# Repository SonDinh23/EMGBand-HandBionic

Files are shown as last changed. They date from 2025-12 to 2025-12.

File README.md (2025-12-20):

# ✋ EMGBand - Hand Bionic

<p align="center">
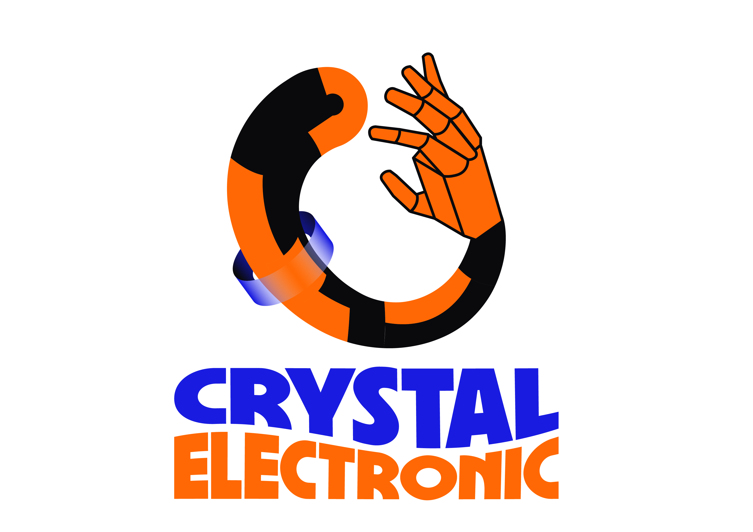
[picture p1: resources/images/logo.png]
EMGBand logo
	<br>
	<strong>Muscle intent in → bionic motion out.</strong>   
</p>

<p align="center">
	
	&nbsp;
	
</p>

EMGBand / Hand Bionic is a full-stack, open hardware kit that turns forearm muscle signals into predictable, servo-safe hand motion. It is built to be hackable, reproducible, and fast to demo: one bill of materials, one firmware pair (ring + hand), one Flutter app to calibrate and ship.

Designed for makers, researchers, and product teams, EMGBand focuses on reliability, safety, and repeatability. The repo bundles manufacturing-ready assets (Gerbers, BOMs), production photos, a tested ESP32 firmware pair, and a Flutter app that makes calibration and demos straightforward.

## Table of Contents
- 🔍 [What this repo delivers](#what-this-repo-delivers)
- 🖼️ [Quick gallery](#quick-gallery)
- 🧭 [Platform at a glance](#platform-at-a-glance)
- ⚙️ [Architecture snapshot](#architecture-snapshot)
- 📚 [Deep dives](#deep-dives)
- 🚀 [Fast start](#fast-start)
- ✨ [Tech highlights](#tech-highlights)
- 📜 [Licence](#licence)
- 🙏 [Thanks](#thanks)

| | | |
| --- | --- | --- |
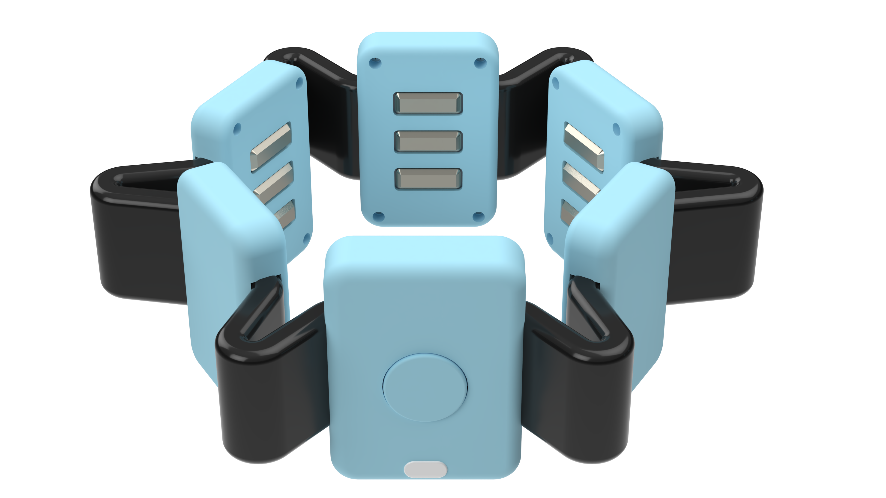
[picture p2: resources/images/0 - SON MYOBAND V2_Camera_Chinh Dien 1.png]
MyoBand front
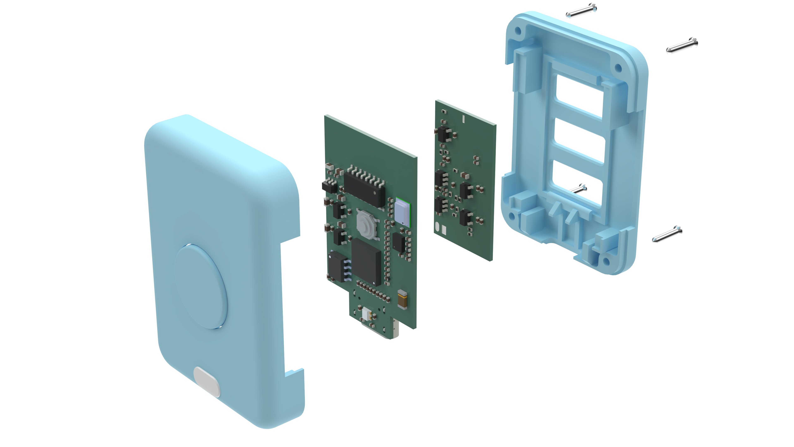
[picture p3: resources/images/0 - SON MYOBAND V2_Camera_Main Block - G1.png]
Main block
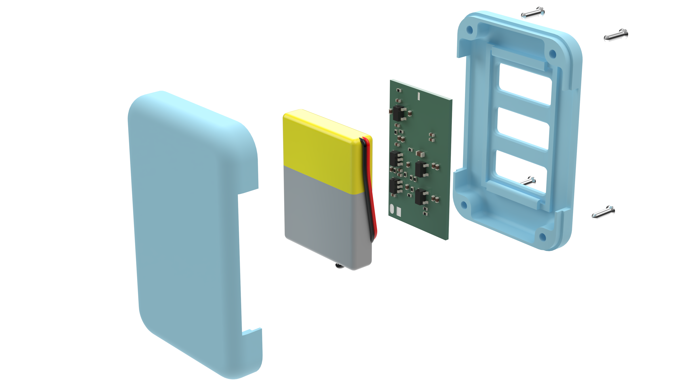
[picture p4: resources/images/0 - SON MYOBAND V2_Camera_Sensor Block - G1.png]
Sensor block
|  |  |  |

<p align="center"><sub>Wearable EMG ring + controller blocks from the latest build.</sub></p>

## What this repo delivers
- **Hardware you can fabricate**: KiCad projects for the MyoBand EMG front-end, hand controller, and modular sensor blocks. Gerbers, pick-and-place, and reference photos are ready for a quick manufacturing turn.
- **Firmware that guards the hardware**: ESP32 (ring + hand) stack with EMG filtering, intent classification, BLE services, OTA hooks, and stall-safe servo control so experiments stay repeatable and safe.
- **App that closes the loop**: Flutter client to scan, pair, stream EMG, calibrate thresholds (Line/Radar), push configs, and swap control modes without reflashing.
- **Media to build confidence**: Photos and demo videos to set assembly expectations before you order or solder.

## Quick gallery

See how the wearable comes together before diving into schematics or code.

| | | |
| --- | --- | --- |
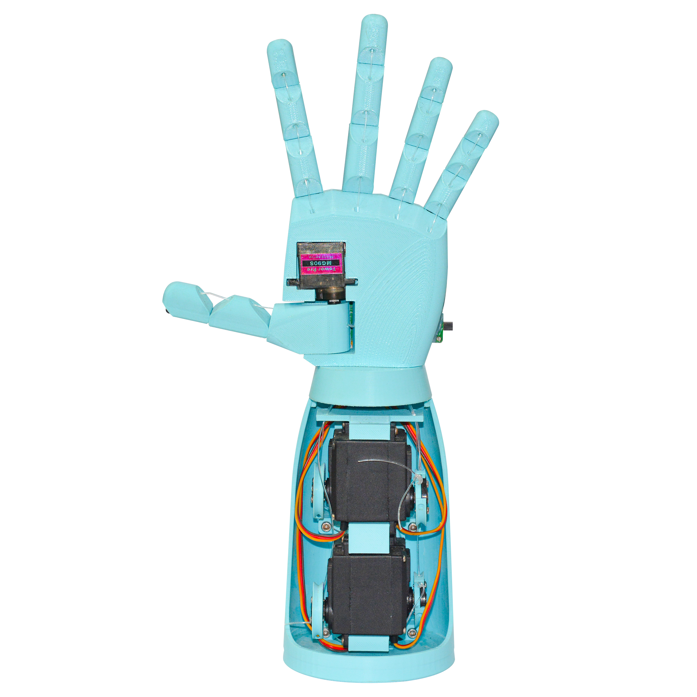
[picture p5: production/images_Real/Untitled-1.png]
Real build 1
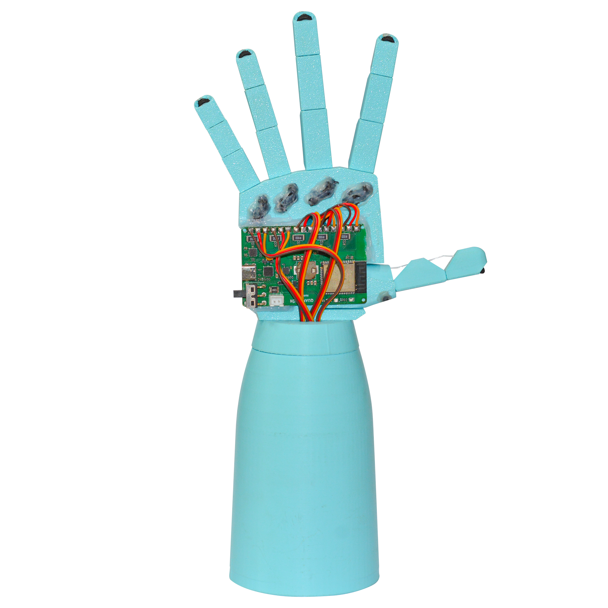
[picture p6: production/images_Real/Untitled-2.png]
Real build 2
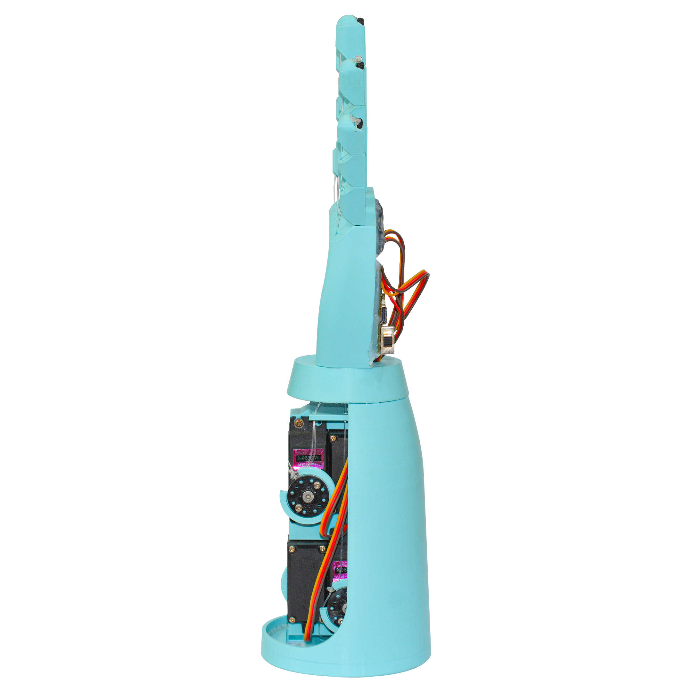
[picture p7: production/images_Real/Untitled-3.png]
Real build 3
| <br><small>📸 Assembled unit 1</small> | <br><small>📸 Assembled unit 2</small> | <br><small>📸 Assembled unit 3</small> |
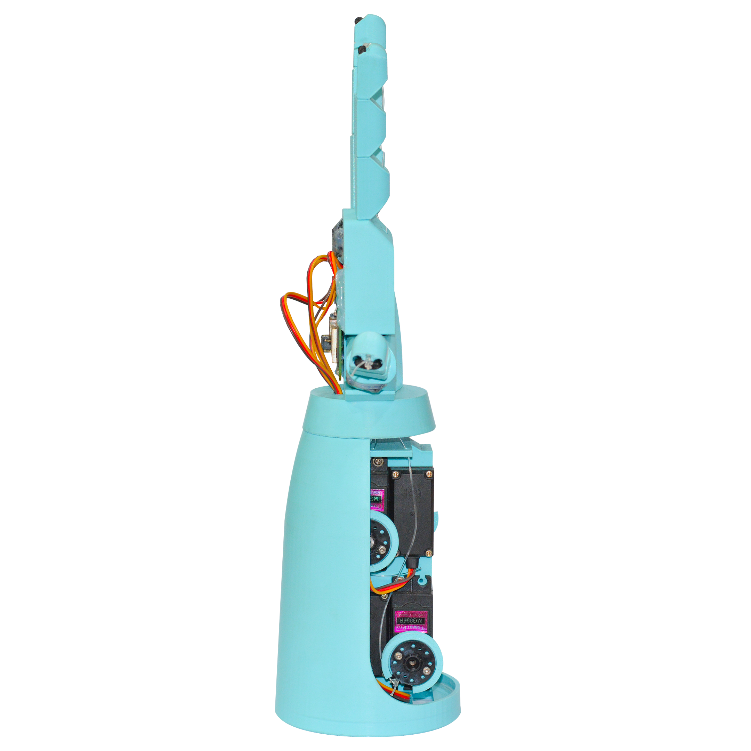
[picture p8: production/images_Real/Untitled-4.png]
Real build 4
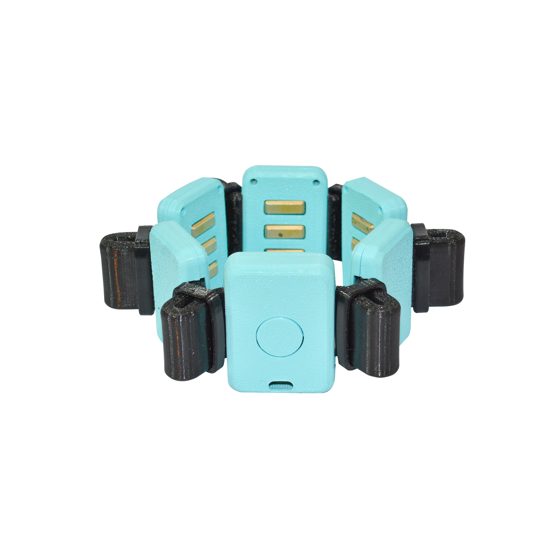
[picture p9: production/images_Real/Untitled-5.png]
Real build 5
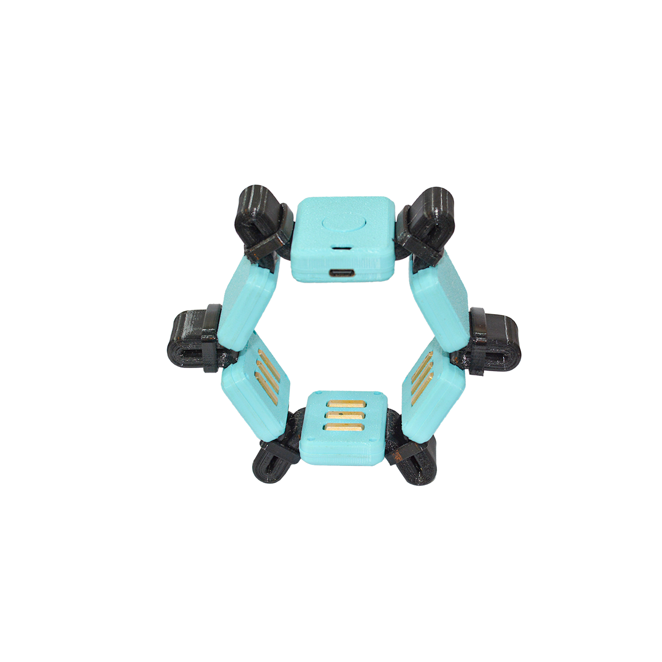
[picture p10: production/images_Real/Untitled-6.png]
Real build 6
| <br><small>🖼️ Side profile</small> | <br><small>🔬 Sensor block close-up</small> | <br><small>🔗 Strap view</small> |

<p align="center"><strong>Live demo videos</strong></p>
<p align="center">
	<video src="resources/video/Demo1.mp4" width="360" controls muted></video>
	<video src="resources/video/Demo2.mp4" width="360" controls muted></video>
</p>

<p align="center"><small>If embeds do not autoplay in your viewer, use the direct links: <a href="resources/video/Demo1.mp4">Demo1.mp4</a> · <a href="resources/video/Demo2.mp4">Demo2.mp4</a>.</small></p>

## Platform at a glance

| Layer | Highlights |
| --- | --- |
| 🛠️ **Hardware** | Low-noise EMG front-end, modular controller blocks, ready-to-manufacture assets, BOMs aligned to the photos you see. |
| 🧠 **Firmware** | ESP32 (ring + hand), FreeRTOS, NimBLE, OTA-ready, Line/Radar classifiers, servo current and motion guards to avoid stalls. |
| 📱 **App** | Flutter UX for BLE JSON control, half-float EMG streaming, auto pair/connect, per-user calibration, and live plots. |

## Architecture snapshot

Signal path in two stages: capture and clean EMG on the ring, classify intent and drive actuators on the hand controller. Calibration data lives in the app and syncs over BLE when you change modes.

<table>
	<tr>
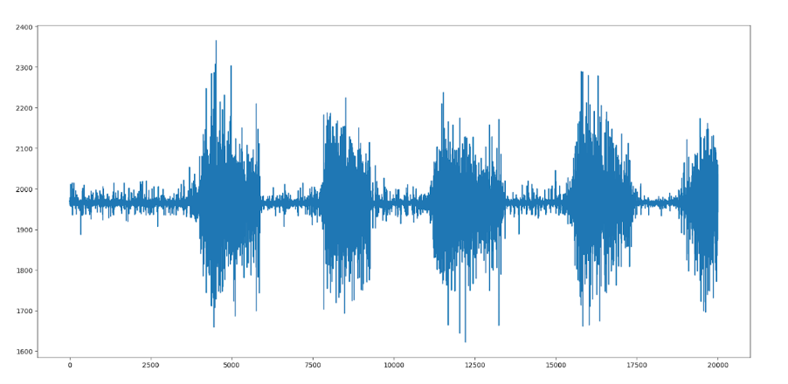
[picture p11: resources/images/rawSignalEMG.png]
Raw EMG
		<td align="center"><br><small>⚡ Raw EMG capture</small></td>
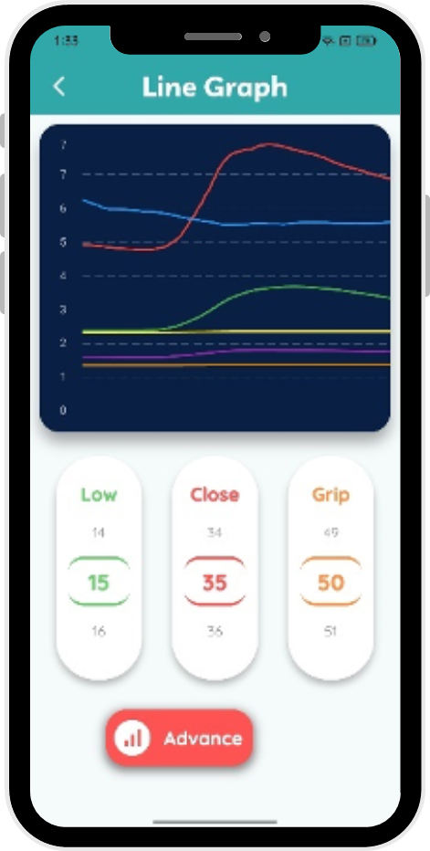
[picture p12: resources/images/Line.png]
Line mode
			<td align="center"><br><small>🔎 Line thresholds</small></td>
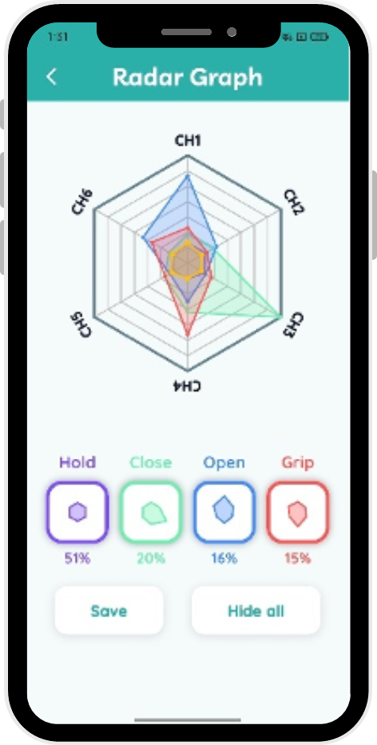
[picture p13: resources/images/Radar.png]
Radar mode
			<td align="center"><br><small>🔁 Radar/Spider matching</small></td>
	</tr>
	<tr>
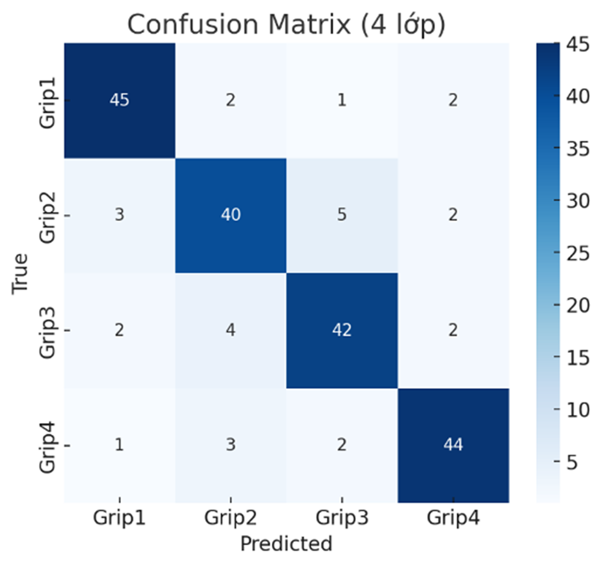
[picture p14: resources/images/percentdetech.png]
Detection percent
		<td align="center"><br><small>✅ Match confidence</small></td>
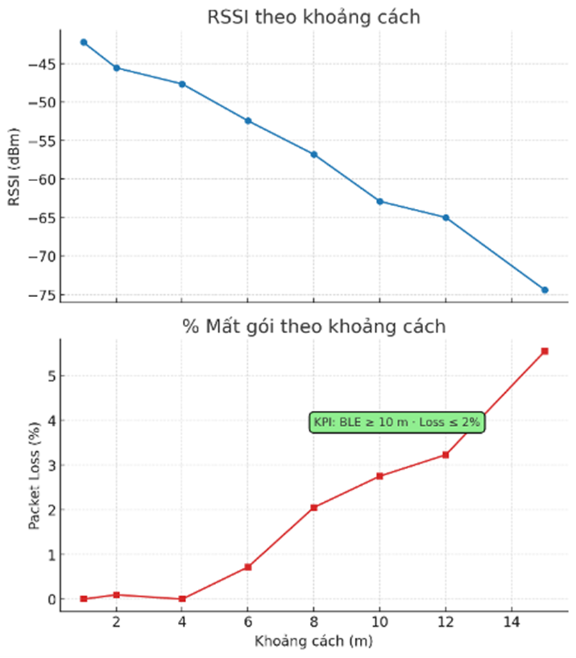
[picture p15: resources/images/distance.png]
Distance metric
		<td align="center"><br><small>➖ Similarity metric</small></td>
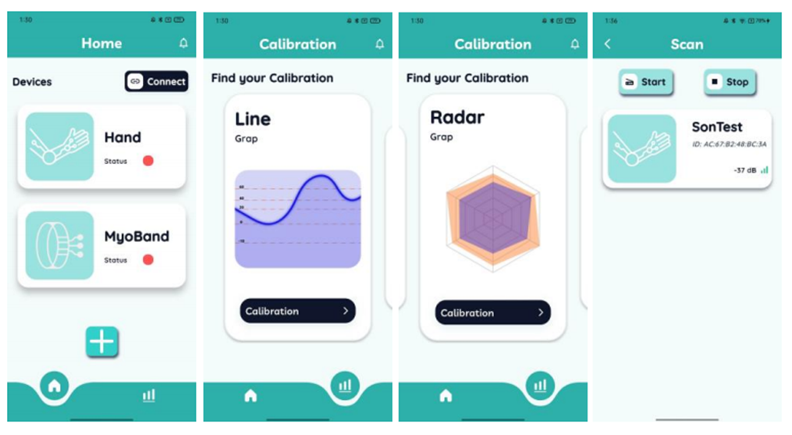
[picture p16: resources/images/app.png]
App UI
		<td align="center"><br><small>📱 Flutter app in action</small></td>
	</tr>
</table>

## Deep dives
- Hardware overview, IC map, and board variants: [hardware/README.md](hardware/README.md)
- Firmware flow, EMG filters/classifiers, BLE/OTA services: [firmware/README.md](firmware/README.md)
- App BLE flows, JSON protocol, half-float decode, and UI cues: [app/README.md](app/README.md)

## Fast start
1) **Fabricate / assemble**: pick your board set from [hardware](hardware/README.md); use the included Gerbers and assembly files to keep builds consistent with the photos.
2) **Flash firmware**: open `firmware/Embedded` in VS Code + PlatformIO, select the target (ring/hand), and run `pio run -t upload`.
3) **Pair with the app**: run the Flutter app (see [app/README.md](app/README.md)), scan and save Hand + MyoBand, then start EMG streaming.
4) **Calibrate deliberately**: choose Line or Radar, adjust thresholds/templates, push to devices, and watch the live plots to confirm stability.
5) **Demo safely**: use the stall/over-activity protections while you tune grip strength or motion ranges.

## Tech highlights
- Half-precision EMG streaming keeps BLE lean; float32 reconstruction happens in the app for analysis.
- Dual control modes: Line (summed thresholds for fast response) and Radar/Spider (template similarity, ≥70% match) for finer intent mapping.
- Safety nets: relax-before-use gating, over-activity clamps, current-based stall detection on servos, watchdog-backed tasks, and OTA hooks for quick fixes.
- UX polish: LED/buzzer cues, auto reconnect, smoothed charts, per-grip calibration profiles, and JSON-based control that is easy to script.

## Licence

This project is licensed under the GNU GPLv3.  
Compared to permissive licences like MIT, GPLv3 requires that if you modify this code and distribute your version (including in commercial products), you must also release your changes under the same GPLv3 licence and provide the corresponding source code.  

This way, everyone can benefit from improvements built on top of this project.  
If this licence causes issues for your intended use, feel free to contact me – I’m open to discussing alternatives.

## Thanks

Huge thanks to contributors, early testers, and the open-source toolchains that made this build possible. Enjoy hacking, and share what you build.

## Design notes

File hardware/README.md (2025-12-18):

# 🔧 Hardware Reference

The definitive pit stop for every PCB in the EMGBand/Hand Bionic stack. Each section tells you what the board does, how it talks to the rest, where to grab build assets, and what to check before you power it up—plus a gallery pulled straight from the committed files.

## 📌 At-a-glance

| Board | Role | Primary interfaces | Manufacturing kit |
| --- | --- | --- | --- |
| [Hand_main](#hand_main) | Bionic hand controller, Wi-Fi/BLE, power/rail monitor | USB-C, UART, GPIO, RGB LED | `Hand_main/*.kicad_*`, top/bottom photos |
| [myoband_main](#myoband_main) | Wearable hub for EMG/IMU/mic, power + comms | USB-UART, Wi-Fi/BLE, SPI/I2C/I2S, ADC | `myoband_main/*.kicad_*`, top/bottom photos |
| [myoBand_emg](#myoBand_emg) | EMG front-end with INA333 multi-stage filtering | Differential electrodes → analog out | `myoBand_emg/*.kicad_*`, top/bottom photos |
| [myoBand_emg_Renesas v0.2](#myoBand_emg_renesas-v02) | EMG front-end using ISL28533 | Differential electrodes → analog out | `myoBand_emg_Renesas/myoBand_emg_v0_2/*.kicad_*` |
| [myoBand_emg_Simulation](#myoBand_emg_simulation) | EMG filter/response simulation | N/A (SPICE) | `myoBand_emg_Simulation/*.kicad_*` |

---

## 🧠 Hand_main

### Highlights
- ESP32-WROOM-32D brain with Wi-Fi/BLE and a status RGB LED to keep you informed at a glance.
- INA3221 keeps eyes on three rails, so servos and external loads stay within safe current/voltage envelopes.
- TPS54620 buck + XC6220 LDO make clean rails; CP2102N USB–UART streamlines flashing and debug.

### Quick specs

| Parameter | Detail |
| --- | --- |
| MCU | ESP32-WROOM-32D |
| Power | Buck 5V→system, 3V3 LDO |
| Power monitor | INA3221 (3 channels) |
| Interfaces | USB-C/CP2102N, GPIO headers, WS2812 data |

### Manufacturing files
- [Hand_main/Hand_main.kicad_sch](Hand_main/Hand_main.kicad_sch)
- [Hand_main/Hand_main.kicad_pcb](Hand_main/Hand_main.kicad_pcb)
- [Hand_main/Hand_main.pdf](Hand_main/Hand_main.pdf)

### Build & test checklist
- Double-check buck polarity and place L/C exactly as laid out to keep EMI tame.
- Probe buck and 3V3 rails before seating the ESP32 or any sensitive loads.
- Confirm USB-C orientation/UART lines, then sanity-check INA3221 readings with a dummy load.

### Gallery

<table>
	<tr>
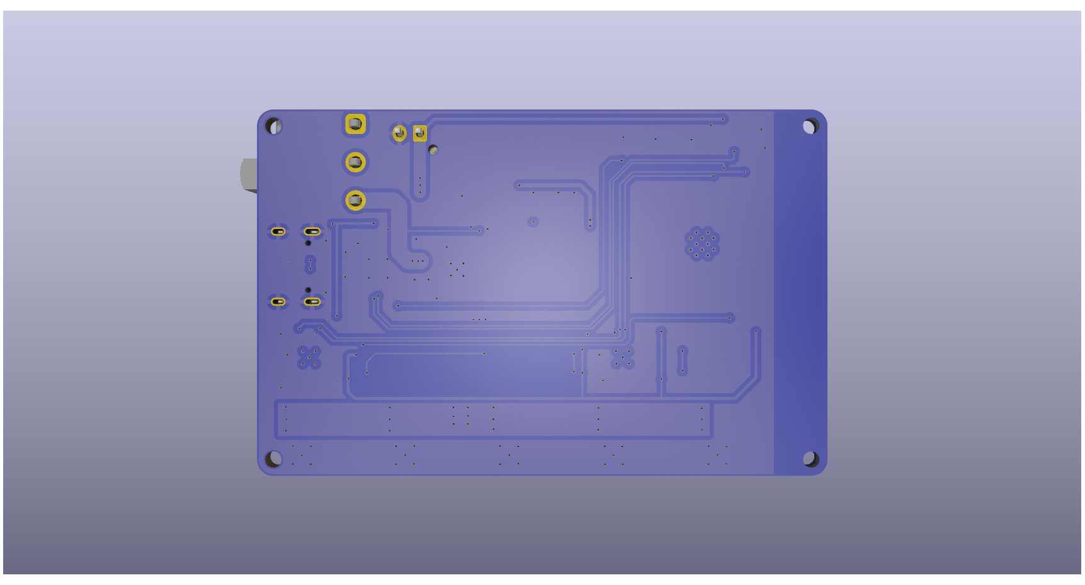
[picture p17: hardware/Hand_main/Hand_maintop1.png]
Hand_main top 1
		<td align="center"><br><small>Top — overview</small></td>
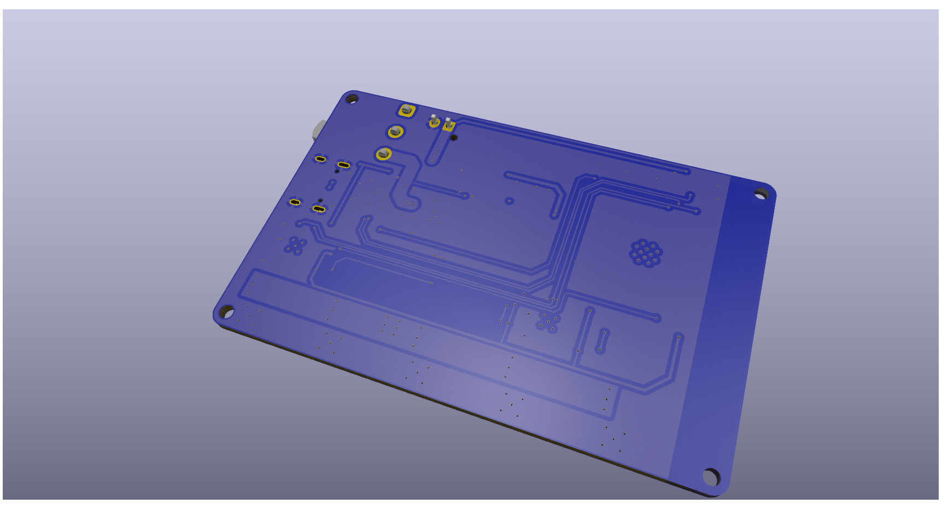
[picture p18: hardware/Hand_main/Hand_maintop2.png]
Hand_main top 2
		<td align="center"><br><small>Top — ESP32 & power</small></td>
	</tr>
	<tr>
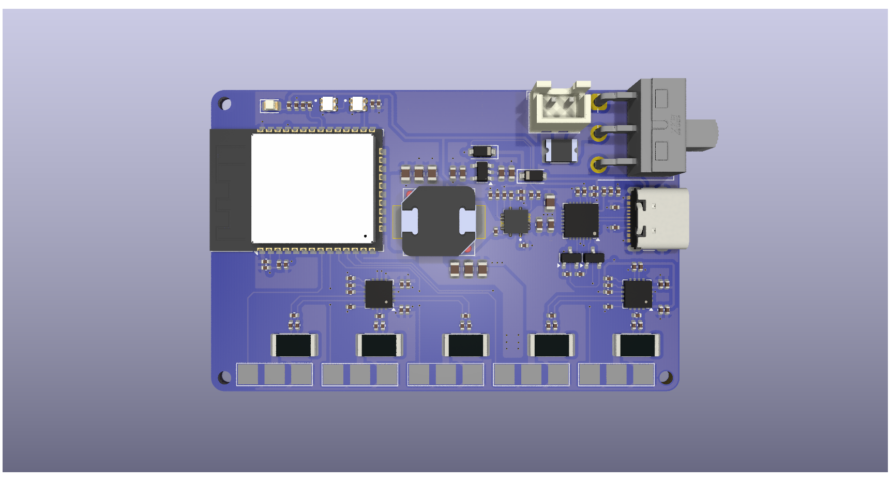
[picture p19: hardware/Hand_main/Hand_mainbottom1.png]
Hand_main bottom 1
		<td align="center"><br><small>Bottom — routing</small></td>
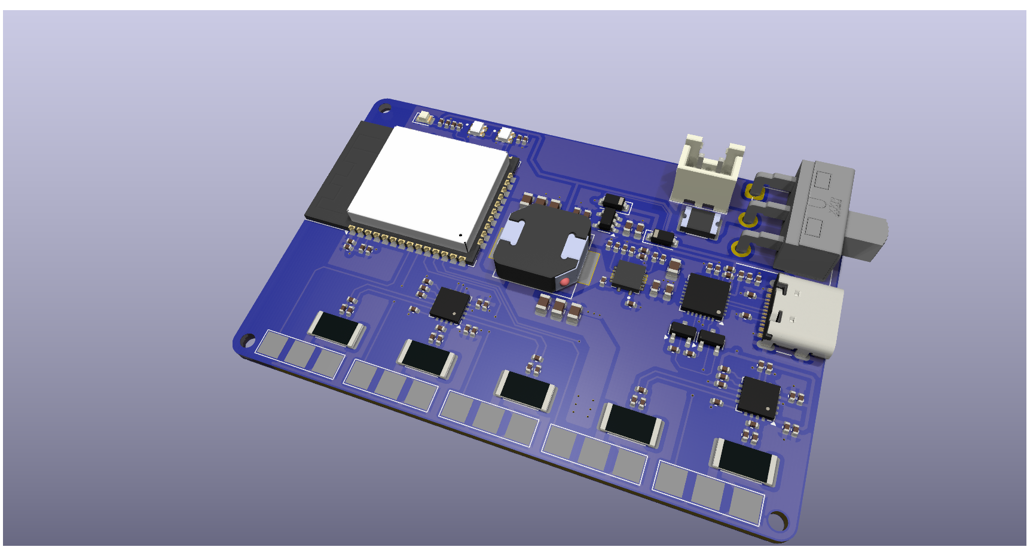
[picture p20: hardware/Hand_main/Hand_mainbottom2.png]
Hand_main bottom 2
		<td align="center"><br><small>Bottom — pours</small></td>
	</tr>
</table>

---

## 🧭 myoband_main

### Highlights
- ESP32-PICO-V3-02 wearable hub that ingests EMG (MCP3208), IMU data (LSM6DSL), and PDM audio (INMP441).
- Power spine: TP4056 Li-ion charger, 3V3 LDO for logic, TPS60402 negative rail for the analog front-end.
- CP2102N handles flashing/debug; WS2812B-2020 signals state; headers expose SPI/I2C/I2S for expansions.

### Quick specs

| Parameter | Detail |
| --- | --- |
| MCU | ESP32-PICO-V3-02 |
| EMG conversion | MCP3208 (12-bit SPI) |
| Sensors | IMU LSM6DSL, mic INMP441 |
| Power | TP4056 charger, 3V3 LDO, TPS60402 negative rail |
| Interfaces | Wi-Fi/BLE, USB-UART, SPI/I2C/I2S, GPIO |

### Manufacturing files
- [myoband_main/myoband_main.kicad_sch](myoband_main/myoband_main.kicad_sch)
- [myoband_main/myoband_main.kicad_pcb](myoband_main/myoband_main.kicad_pcb)
- [myoband_main/myoband_main.pdf](myoband_main/myoband_main.pdf)

### Build & test checklist
- Inspect TP4056 charge path and battery polarity; watch thermals at higher charge currents.
- Verify the TPS60402 negative rail before biasing the EMG analog stage.
- Smoke-test everything together: Wi-Fi/BLE, SPI EMG ADC, I2C IMU, PDM mic—and listen for noise coupling.

### Gallery

<table>
	<tr>
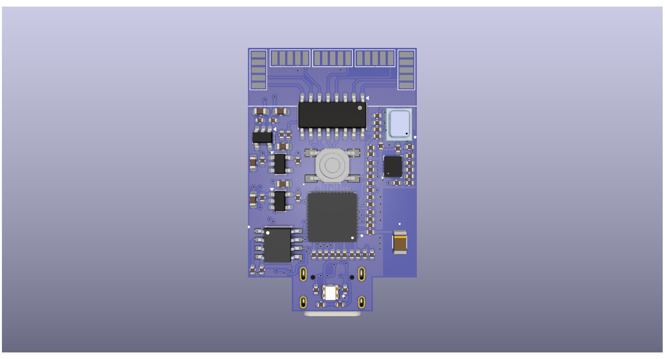
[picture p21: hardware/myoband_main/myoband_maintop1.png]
myoband_main top 1
		<td align="center"><br><small>Top — overview</small></td>
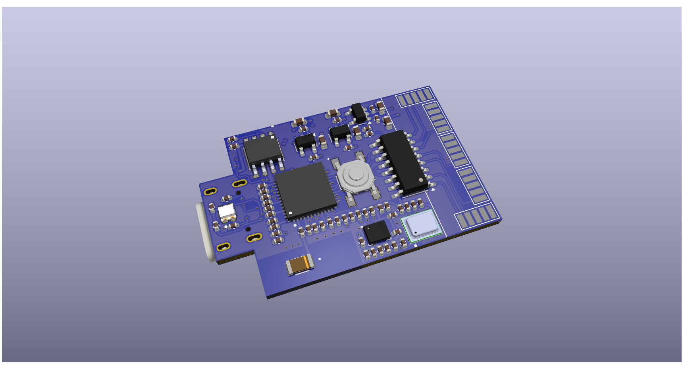
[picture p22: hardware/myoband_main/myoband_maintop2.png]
myoband_main top 2
		<td align="center"><br><small>Top — MCU & IO</small></td>
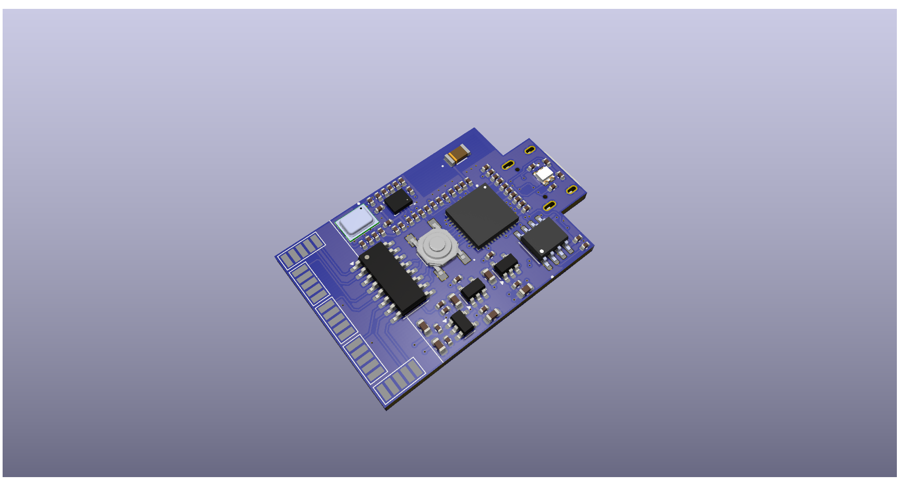
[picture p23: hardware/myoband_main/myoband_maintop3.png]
myoband_main top 3
		<td align="center"><br><small>Top — power/charger</small></td>
	</tr>
	<tr>
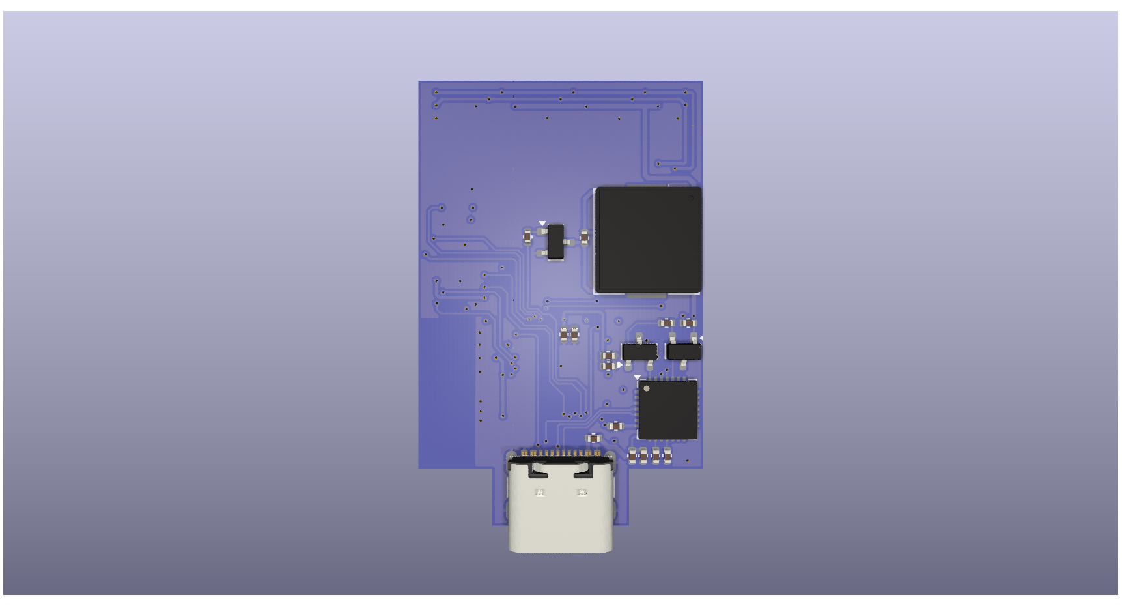
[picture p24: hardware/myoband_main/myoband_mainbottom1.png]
myoband_main bottom 1
		<td align="center"><br><small>Bottom — routing</small></td>
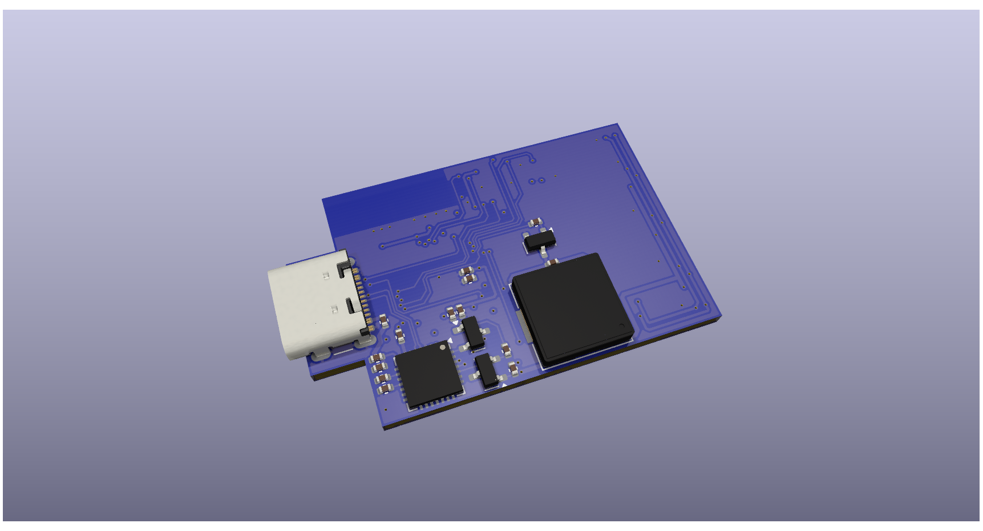
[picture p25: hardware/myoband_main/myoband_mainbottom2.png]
myoband_main bottom 2
		<td align="center"><br><small>Bottom — pours</small></td>
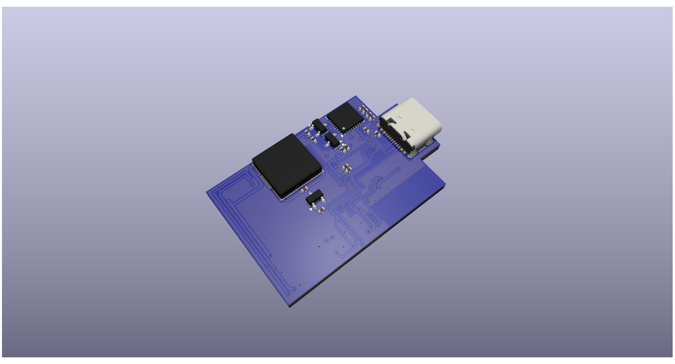
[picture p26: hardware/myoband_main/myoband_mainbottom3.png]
myoband_main bottom 3
		<td align="center"><br><small>Bottom — placement</small></td>
	</tr>
</table>

---

## 🩺 myoBand_emg (INA333)

### Highlights
- INA333-based EMG front-end for low-noise differential gain, feeding MCP601 stages for band-pass/notch shaping.
- TPS60402 negative rail preserves headroom and keeps distortion low at higher amplitudes.
- Layout favors short electrode runs and clean analog planes away from digital chatter.

### Quick specs

| Parameter | Detail |
| --- | --- |
| Instrumentation amp | INA333 |
| Filter op-amp | MCP601 (multi-stage) |
| Power | Negative rail via TPS60402, bias/offset via R/C network |
| Output | Analog to ADC (e.g., MCP3208 on myoband_main) |

### Manufacturing files
- [myoBand_emg/EMG_SENSOR.kicad_sch](myoBand_emg/EMG_SENSOR.kicad_sch)
- [myoBand_emg/EMG_SENSOR.kicad_pcb](myoBand_emg/EMG_SENSOR.kicad_pcb)
- [myoBand_emg/EMG_SENSOR.pdf](myoBand_emg/EMG_SENSOR.pdf)

### Build & test checklist
- Match R/C values to your target corners; confirm INA333 orientation and gain resistors.
- Measure the negative rail before attaching electrodes; verify mid-bias to avoid clipping.
- Characterize baseline noise; notch the mains band or add ferrites if hum shows up.

### Gallery

<table>
	<tr>
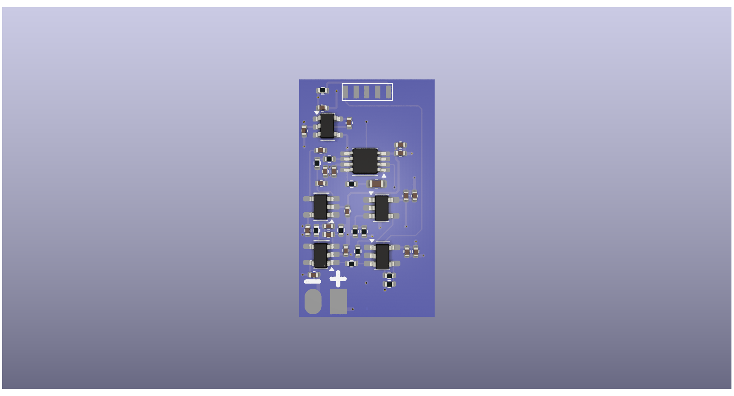
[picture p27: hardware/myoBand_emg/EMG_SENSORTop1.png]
EMG_SENSOR top 1
		<td align="center"><br><small>Top — overview</small></td>
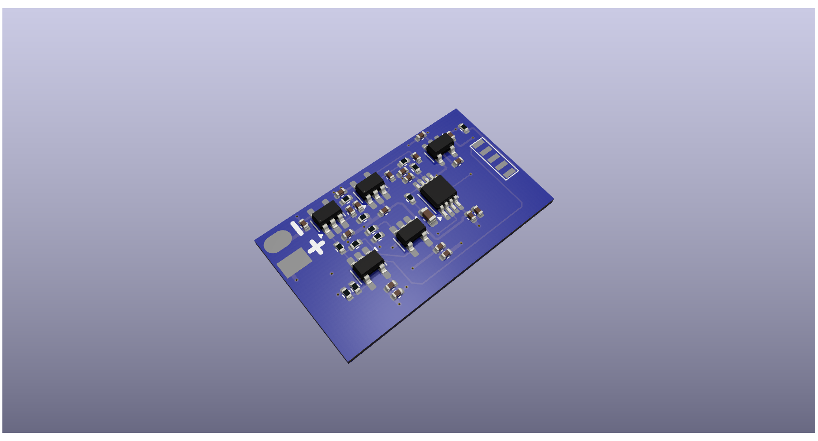
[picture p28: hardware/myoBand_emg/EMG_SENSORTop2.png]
EMG_SENSOR top 2
		<td align="center"><br><small>Top — amp/filter</small></td>
	</tr>
	<tr>
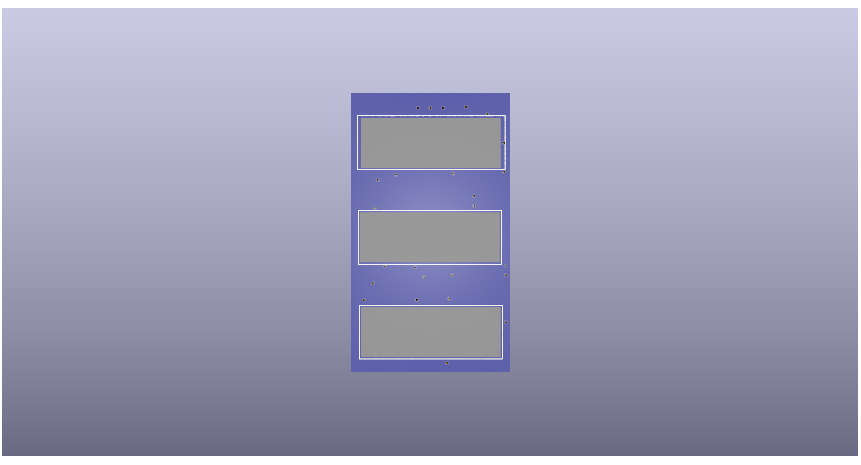
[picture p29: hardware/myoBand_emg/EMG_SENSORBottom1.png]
EMG_SENSOR bottom 1
		<td align="center"><br><small>Bottom — routing</small></td>
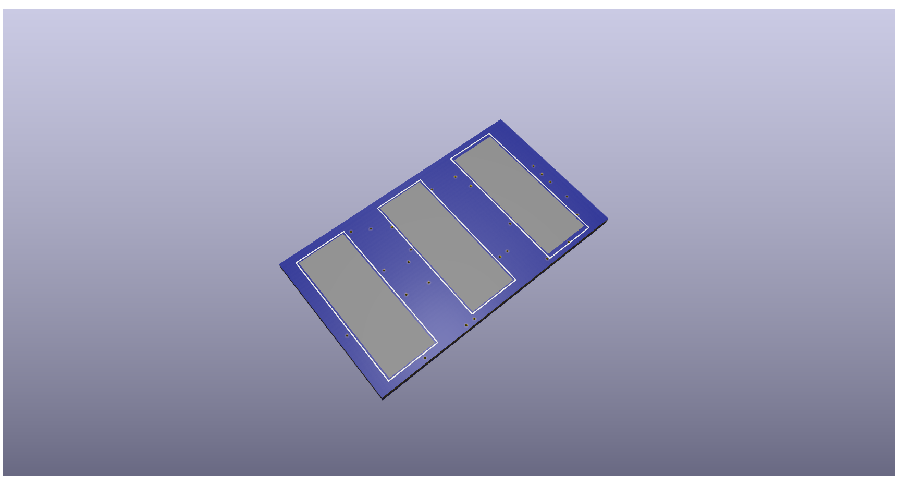
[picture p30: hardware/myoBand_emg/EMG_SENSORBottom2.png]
EMG_SENSOR bottom 2
		<td align="center"><br><small>Bottom — pours</small></td>
	</tr>
</table>

---

## 🩺 myoBand_emg_Renesas v0.2 (ISL28533)

### Highlights
- Renesas ISL28533 variant for a broader dynamic range and lower noise floor.
- MCP601 stack still handles staged gain and filtering; rails/bias come from the hub via R/C network.
- Same disciplined layout: short electrode routes, isolated analog plane, test-points where you need them.

### Quick specs

| Parameter | Detail |
| --- | --- |
| Instrumentation amp | ISL28533 |
| Filter op-amp | MCP601 |
| Power | Rails/bias from hub or external (no onboard charge pump) |
| Output | Analog to hub ADC |

### Manufacturing files
- [myoBand_emg_Renesas/myoBand_emg_v0_2/myoBand_emg_v0_2.kicad_sch](myoBand_emg_Renesas/myoBand_emg_v0_2/myoBand_emg_v0_2.kicad_sch)
- [myoBand_emg_Renesas/myoBand_emg_v0_2/myoBand_emg_v0_2.kicad_pcb](myoBand_emg_Renesas/myoBand_emg_v0_2/myoBand_emg_v0_2.kicad_pcb)
- [myoBand_emg_Renesas/myoBand_emg_v0_2/myoBand_emg_v0_2.pdf](myoBand_emg_Renesas/myoBand_emg_v0_2/myoBand_emg_v0_2.pdf)

### Build & test checklist
- Validate mid-rail bias when powered from the hub; confirm ISL28533 headroom at your chosen gain.
- A/B noise against the INA333 build to choose the production winner.
- Drop in renders/photos once assembled to lock placement confidence.

### Gallery
- No images in this folder yet; drop in PNG/JPG renders or photos when ready.

---

## 🧪 myoBand_emg_Simulation

### Highlights
- SPICE sandbox to shape EMG gain and filter response before you spend copper.
- Ideal sources and R/C only—no production silicon here.

### Quick specs

| Parameter | Detail |
| --- | --- |
| Purpose | Frequency/gain/notch simulation |
| Components | Ideal sources, R/C |
| Output | Simulated waveforms |

### Files
- [myoBand_emg_Simulation/myoBand_emg_Simulation.kicad_sch](myoBand_emg_Simulation/myoBand_emg_Simulation.kicad_sch)
- [myoBand_emg_Simulation/myoBand_emg_Simulation.kicad_pcb](myoBand_emg_Simulation/myoBand_emg_Simulation.kicad_pcb)

---

## 🖼️ Image & path guidance

- Use forward slashes `/` in image paths; links are relative to this README.
- Example: `![EMG front](myoBand_emg/EMG_SENSORTop1.png)`.
- GitHub renders images once the PNG files are present; add new renders/photos in the matching board folder.
- Prefer per-board READMEs or a PDF gallery? Say the word and we will scaffold it.

---

_Last refreshed: check git history for the latest author/date._

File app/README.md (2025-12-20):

# 📱 EMGBand App

Your cockpit for the EMGBand/Hand Bionic stack. It pairs the Hand controller and the MyoBand EMG ring, streams six channels of muscle data in real time, lets you shape thresholds (Line or Radar), and flips control modes on the fly—using lean BLE with JSON commands and half-float payloads.

## What you can do
- One-tap scan, remember, and auto-connect to Hand + MyoBand.
- Stream six-channel EMG with smoothed, throttled charts that stay responsive.
- Calibrate two paradigms: Line (sum thresholds) and Radar/“Spider” (per-grip templates).
- Flip EMG control mode (Line ↔ Radar) and push thresholds instantly.
- Check battery/state; OTA UUIDs are already wired for upcoming updates.

## BLE architecture
- UUID catalog: [app/app_emg/lib/BLE/Service/bleService.dart](app/app_emg/lib/BLE/Service/bleService.dart) holds all Hand/MyoBand services and characteristics (setting, state, battery, OTA...).
- Scan UI: [app/app_emg/lib/BLE/UI/scanDevice.dart](app/app_emg/lib/BLE/UI/scanDevice.dart) filters by UUID, saves picks via SharedPreferences, and lists candidates.
- Connection orchestrator: [app/app_emg/lib/BLE/UI/deviceUser.dart](app/app_emg/lib/BLE/UI/deviceUser.dart) auto-connects saved devices, stops scanning when both are up, and kicks off discovery.
- Discovery & handles: [app/app_emg/lib/BLE/Service/myobandProcess.dart](app/app_emg/lib/BLE/Service/myobandProcess.dart) captures setting/battery/control characteristics and subscribes for EMG + telemetry.
- JSON link layer: [app/app_emg/lib/BLE/Helper/ManageJson.dart](app/app_emg/lib/BLE/Helper/ManageJson.dart) wraps UTF-8 encode/decode with retry/backoff; every command carries mode/type/val to mirror firmware parsing.

## EMG data path
1) Firmware packs EMG frames as float16 to shrink BLE payloads.
2) App receives little-endian uint16 words and expands with `halfToFloat` in [app/app_emg/lib/BLE/Helper/ConvertNum.dart](app/app_emg/lib/BLE/Helper/ConvertNum.dart): split sign/exp/mantissa, handle zero/subnormal/Inf/NaN, rebuild float32 bits, then read via ByteData.
3) Values are lightly low-pass smoothed and plotted live (fl_chart) in the calibration views.

## Calibration workflows
- **Line Threshold** ([app/app_emg/lib/BLE/UI/Features/MyoBandFealture/Calib/LineThreshold/lineThreshold.dart](app/app_emg/lib/BLE/UI/Features/MyoBandFealture/Calib/LineThreshold/lineThreshold.dart))
  - Start EMG RMS stream: `{mode:"set", type:"cmd", val:{type:"RMS", state:1}}` to the setting characteristic.
  - Decode EMG, show six channels plus the sum with gentle smoothing.
  - Read thresholds: `{mode:"set", type:"upd", val:"THL"}` → four ints (setup/low/high/grip).
  - Write thresholds: `{mode:"set", type:"cmd", val:{type:"THL", TH:"80:low:high:grip"}}`; UI enforces `low < high < grip`.

- **Radar / Spider** ([app/app_emg/lib/BLE/UI/Features/MyoBandFealture/Calib/RadarThreshold/radarThreshold.dart](app/app_emg/lib/BLE/UI/Features/MyoBandFealture/Calib/RadarThreshold/radarThreshold.dart))
  - Stream EMG RMS, normalize each channel (0..40) to 0..1.
  - Score each of four grip templates: per channel `1 - |c - t| / |t|` clipped to [0,1]; average six channels, accept if ≥70%.
  - Read templates: `{mode:"set", type:"upd", val:"THS"}` → firmware returns 4×6 floats.
  - Write a template: `{mode:"set", type:"cmd", val:{type:"THS", TH:"id@v1:v2:v3:v4:v5:v6"}}`.

- **Switch EMG mode** ([app/app_emg/lib/BLE/UI/DeviceDetail/myobandDetail.dart](app/app_emg/lib/BLE/UI/DeviceDetail/myobandDetail.dart))
  - Send `{mode:"set", type:"cmd", val:{type:"EMGCtrl", state:1|2}}` to pick Line or Radar; read current with `{mode:"set", type:"upd", val:{type:"EMGCtrl"}}`.

## App flow in practice
1) First run: open Scan, find Hand + MyoBand (UUID-filtered), save them for auto-connect.
2) Device screen: tap “Scan/Connect” → the app pairs both, discovers characteristics, and shows live status.
3) Calibrate:
   - Line tab: start stream, watch six channels plus sum, adjust low/high/grip, write back.
   - Radar tab: watch match %, tweak four grip vectors, write back.
4) Switch control mode (Line ↔ Radar) in MyoBand detail when you change paradigms.

## OTA hook
- OTA UUIDs are defined; UI flow is pending. Assets include `update.gif` as a placeholder. Future flow: enter OTA mode, upload image over the OTA characteristic, verify, reboot.

## Assets (for docs/demos)
- Layouts: hand + myoband SVGs [app/app_emg/assets/images/layouts](app/app_emg/assets/images/layouts)
- Calibration illustrations: line/radar/healthy PNGs [app/app_emg/assets/images/calibrate](app/app_emg/assets/images/calibrate)
- GIFs: update/oops [app/app_emg/assets/images/gif](app/app_emg/assets/images/gif)

Example embeds (centered for readability):

<table>
	<tr>
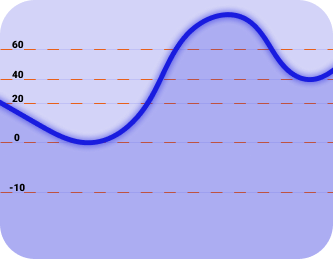
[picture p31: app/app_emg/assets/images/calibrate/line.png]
Line calibration
		<td align="center"><br><small>Line calibration</small></td>
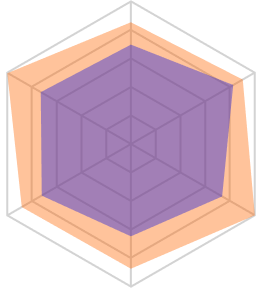
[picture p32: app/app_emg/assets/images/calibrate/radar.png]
Radar calibration
		<td align="center"><br><small>Radar (spider) calibration</small></td>
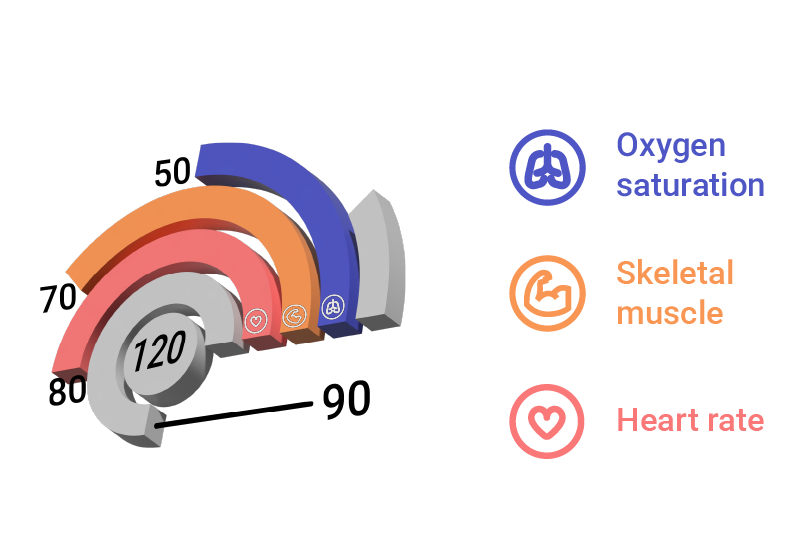
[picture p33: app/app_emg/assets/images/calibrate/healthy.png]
Healthy posture hint
		<td align="center"><br><small>Healthy posture hint</small></td>
	</tr>
</table>

## Source map
- BLE UUIDs/constants: [app/app_emg/lib/BLE/Service/bleService.dart](app/app_emg/lib/BLE/Service/bleService.dart)
- BLE controller/state: [app/app_emg/lib/BLE/Service/bleController.dart](app/app_emg/lib/BLE/Service/bleController.dart)
- MyoBand discovery & handles: [app/app_emg/lib/BLE/Service/myobandProcess.dart](app/app_emg/lib/BLE/Service/myobandProcess.dart)
- Scan UI: [app/app_emg/lib/BLE/UI/scanDevice.dart](app/app_emg/lib/BLE/UI/scanDevice.dart)
- Device connect UI: [app/app_emg/lib/BLE/UI/deviceUser.dart](app/app_emg/lib/BLE/UI/deviceUser.dart)
- EMG Line calibration: [app/app_emg/lib/BLE/UI/Features/MyoBandFealture/Calib/LineThreshold/lineThreshold.dart](app/app_emg/lib/BLE/UI/Features/MyoBandFealture/Calib/LineThreshold/lineThreshold.dart)
- EMG Radar calibration: [app/app_emg/lib/BLE/UI/Features/MyoBandFealture/Calib/RadarThreshold/radarThreshold.dart](app/app_emg/lib/BLE/UI/Features/MyoBandFealture/Calib/RadarThreshold/radarThreshold.dart)
- Half/float conversion: [app/app_emg/lib/BLE/Helper/ConvertNum.dart](app/app_emg/lib/BLE/Helper/ConvertNum.dart)

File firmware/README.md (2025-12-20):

# 🚀 Firmware Stack

Two ESP32s, one bionic experience: the wearable EMG ring senses intent, and the hand controller turns it into motion. This guide focuses on how it works, the algorithms behind it, and why it survives real-world use.

## Topology
- Wearable EMG ring (ESP32-PICO): samples six EMG channels, filters/classifies intent, streams EMG or emits compact control states. See [firmware/Embedded/src/myoBand.cpp](firmware/Embedded/src/myoBand.cpp).
- Hand controller (ESP32-WROOM): scans/pairs to the ring, exposes services to the app, and drives five servos with current feedback. See [firmware/Embedded/src/handMain.cpp](firmware/Embedded/src/handMain.cpp).

## End-to-end flow
1) Ring: MCP3208 → filters → intent classifier in [firmware/Embedded/lib/Son_EMGSensor/EMGSensor.cpp](firmware/Embedded/lib/Son_EMGSensor/EMGSensor.cpp).
2) Ring BLE: advertises EMG, thresholds, mode, battery, and control state via [firmware/Embedded/lib/Son_BLERing/BLEEMGSensor.cpp](firmware/Embedded/lib/Son_BLERing/BLEEMGSensor.cpp) and [firmware/Embedded/lib/Son_BLERing/BLERingManager.cpp](firmware/Embedded/lib/Son_BLERing/BLERingManager.cpp).
3) Hand: acts as BLE central to the ring and peripheral to the app through [firmware/Embedded/lib/Son_BLEHand/BLEHandManager.cpp](firmware/Embedded/lib/Son_BLEHand/BLEHandManager.cpp) and [firmware/Embedded/lib/Son_BLEServiceManager/BLECentralManager.h](firmware/Embedded/lib/Son_BLEServiceManager/BLECentralManager.h).
4) Servo control: states (`open/hold/close/grip`) feed current-aware kinematics in [firmware/Embedded/lib/Son_HandState/HandState.cpp](firmware/Embedded/lib/Son_HandState/HandState.cpp).

## Core algorithms — EMG ring
- Sampling + filters: six MCP3208 channels → high-pass → low-pass smoothing → per-channel Kalman → aggregate magnitude [firmware/Embedded/lib/Son_EMGSensor/EMGSensor.cpp](firmware/Embedded/lib/Son_EMGSensor/EMGSensor.cpp).
- Control modes
	- LINE: sums channel magnitudes against four thresholds (setup/low/high/grip) to output `open/hold/close/grip` [firmware/Embedded/lib/Son_EMGSensor/EMGSensor.cpp](firmware/Embedded/lib/Son_EMGSensor/EMGSensor.cpp).
	- SPIDER: normalizes each channel to four grip templates, scores similarity, and picks the best above the accuracy bar [firmware/Embedded/lib/Son_EMGSensor/EMGSensor.cpp](firmware/Embedded/lib/Son_EMGSensor/EMGSensor.cpp).
- Safety envelope: `waitRelax()` enforces a quiet baseline; `isGetOnHand()` rejects saturated reads; over-activity forces hold and re-enters relax [firmware/Embedded/lib/Son_EMGSensor/EMGSensor.cpp](firmware/Embedded/lib/Son_EMGSensor/EMGSensor.cpp).
- Lean transport: half-precision packing (`converHaftFloat`) trims EMG frames for BLE; thresholds/mode/logic persist in NVS [firmware/Embedded/lib/Son_EMGSensor/EMGSensor.h](firmware/Embedded/lib/Son_EMGSensor/EMGSensor.h).

## Control algorithms — Hand controller
- Five servos, tailored pulse ranges, and dual INA3221 current sensing to halt motion when load thresholds trip—stall-safe by design [firmware/Embedded/lib/Son_HandState/HandState.cpp](firmware/Embedded/lib/Son_HandState/HandState.cpp).
- Modes `Open/Close/Hold/Change` map BLE states (`a/b/c/d`); grip cycling decides which fingers stay driven for each grasp style [firmware/Embedded/lib/Son_HandState/HandState.cpp](firmware/Embedded/lib/Son_HandState/HandState.cpp).
- Speed presets and RGB cues live in NVS; LEDs mirror connection and control state for instant field feedback [firmware/Embedded/lib/Son_HandState/HandState.cpp](firmware/Embedded/lib/Son_HandState/HandState.cpp).

## Tasking & real-time behavior
- EMG ring tasks [firmware/Embedded/src/myoBand.cpp](firmware/Embedded/src/myoBand.cpp):
	- `ReadSensorOP`: 1 kHz EMG sync + LED cue.
	- `ReadSensorBLEOP`: EMG BLE notify + periodic control state push.
	- `ModeOP`: battery notifications and control deltas.
	- `RingOP`: swaps advertising/streaming, respects OTA, manages sleep/wake.
- Hand controller tasks [firmware/Embedded/src/handMain.cpp](firmware/Embedded/src/handMain.cpp):
	- `BleMasterOp`: scan/connect to ring, blink status RGB.
	- `ControlOp`: 1 ms sensor/servo update loop.
	- Main loop: toggles OTA-safe state and suspends tasks when flashing.

## BLE + OTA
- Ring: EMG stream, thresholds, logic mode, battery, and control state; JSON writes set thresholds/mode; OTA-safe path baked in [firmware/Embedded/lib/Son_BLERing/BLEEMGSensor.cpp](firmware/Embedded/lib/Son_BLERing/BLEEMGSensor.cpp).
- Hand: publishes control/info to the app while central to the ring; OTA mode pauses control tasks to keep flash safe [firmware/Embedded/src/handMain.cpp](firmware/Embedded/src/handMain.cpp).

### JSON command/response shape
- Control channel speaks JSON strings over BLE characteristics. The `mode`/`type` fields gate actions; `val.type` selects payload (logic mode, line thresholds, spider templates, EMG control).
- Line thresholds: `THRESHOLD_LINE_JSON` carries four ints (setup/low/high/grip); spider templates: `THRESHOLD_SPIDER_JSON` parses `grip@f1:f2:f3:f4:f5:f6` into six floats per grip [firmware/Embedded/lib/Son_BLERing/BLEEMGSensor.cpp](firmware/Embedded/lib/Son_BLERing/BLEEMGSensor.cpp).
- Reads use `encode()` to serialize current settings; writes use `decode()`/`sendSetting()` to apply and persist to NVS, then optionally reboot when control mode changes.

### Binary efficiency (half-float packing)
- EMG frames are packed as IEEE 754 half-precision via `floatToHaft()` in [firmware/Embedded/lib/Son_Filter/Son_Utils.h](firmware/Embedded/lib/Son_Filter/Son_Utils.h) and sent as 12-byte notify (6 channels + timestamp) [firmware/Embedded/lib/Son_EMGSensor/EMGSensor.cpp](firmware/Embedded/lib/Son_EMGSensor/EMGSensor.cpp).
- On the receiver (app/hand), expand each 16-bit half to float32 to reconstruct magnitudes; control states remain single-byte to keep latency minimal.

### OTA discipline
- Both nodes reserve an OTA state: the hand’s main loop suspends BLE master and control tasks before flashing; the ring halts streaming/advertising when OTA is requested to protect flash writes.
- Keep MTU negotiated (517) before large transfers and avoid long-running callbacks during OTA; watchdog remains armed to recover from stalled uploads.

## Power, UX, and safety
- Ring: button-controlled deep sleep, charger guard, battery percent with low-batt tones/LED, mic/LED gating, WDT on critical loops [firmware/Embedded/src/myoBand.cpp](firmware/Embedded/src/myoBand.cpp).
- Hand: per-finger stall prevention via current sensing, RGB for connection/OTA, conservative servo steps to protect mechanics [firmware/Embedded/lib/Son_HandState/HandState.cpp](firmware/Embedded/lib/Son_HandState/HandState.cpp).

## Why this stack is strong
- Robust by design: enforced relax-before-use, over-activity clamp, stall-aware servos, watchdog-backed tasks.
- BLE-efficient: half-float frames, tuned MTU, tiny control states, dual-role topology (central + peripheral).
- Field-friendly: thresholds/modes/speeds live in NVS; LEDs/buzzer narrate state; OTA on both nodes keeps updates painless.
- Modular: EMG processing, BLE transport, hand kinematics, and alerts are isolated libraries—swap or tune without domino effects.

## Build & flash
- Uses PlatformIO (`platformio.ini` in `firmware/Embedded`). Typical flow: `pio run -t upload` from the `Embedded` folder, selecting the appropriate environment for ring vs hand.

## Quick file map
- Ring runtime: [firmware/Embedded/src/myoBand.cpp](firmware/Embedded/src/myoBand.cpp)
- EMG processing: [firmware/Embedded/lib/Son_EMGSensor/EMGSensor.cpp](firmware/Embedded/lib/Son_EMGSensor/EMGSensor.cpp)
- Ring BLE services: [firmware/Embedded/lib/Son_BLERing/BLEEMGSensor.cpp](firmware/Embedded/lib/Son_BLERing/BLEEMGSensor.cpp)
- Hand runtime: [firmware/Embedded/src/handMain.cpp](firmware/Embedded/src/handMain.cpp)
- Hand kinematics: [firmware/Embedded/lib/Son_HandState/HandState.cpp](firmware/Embedded/lib/Son_HandState/HandState.cpp)

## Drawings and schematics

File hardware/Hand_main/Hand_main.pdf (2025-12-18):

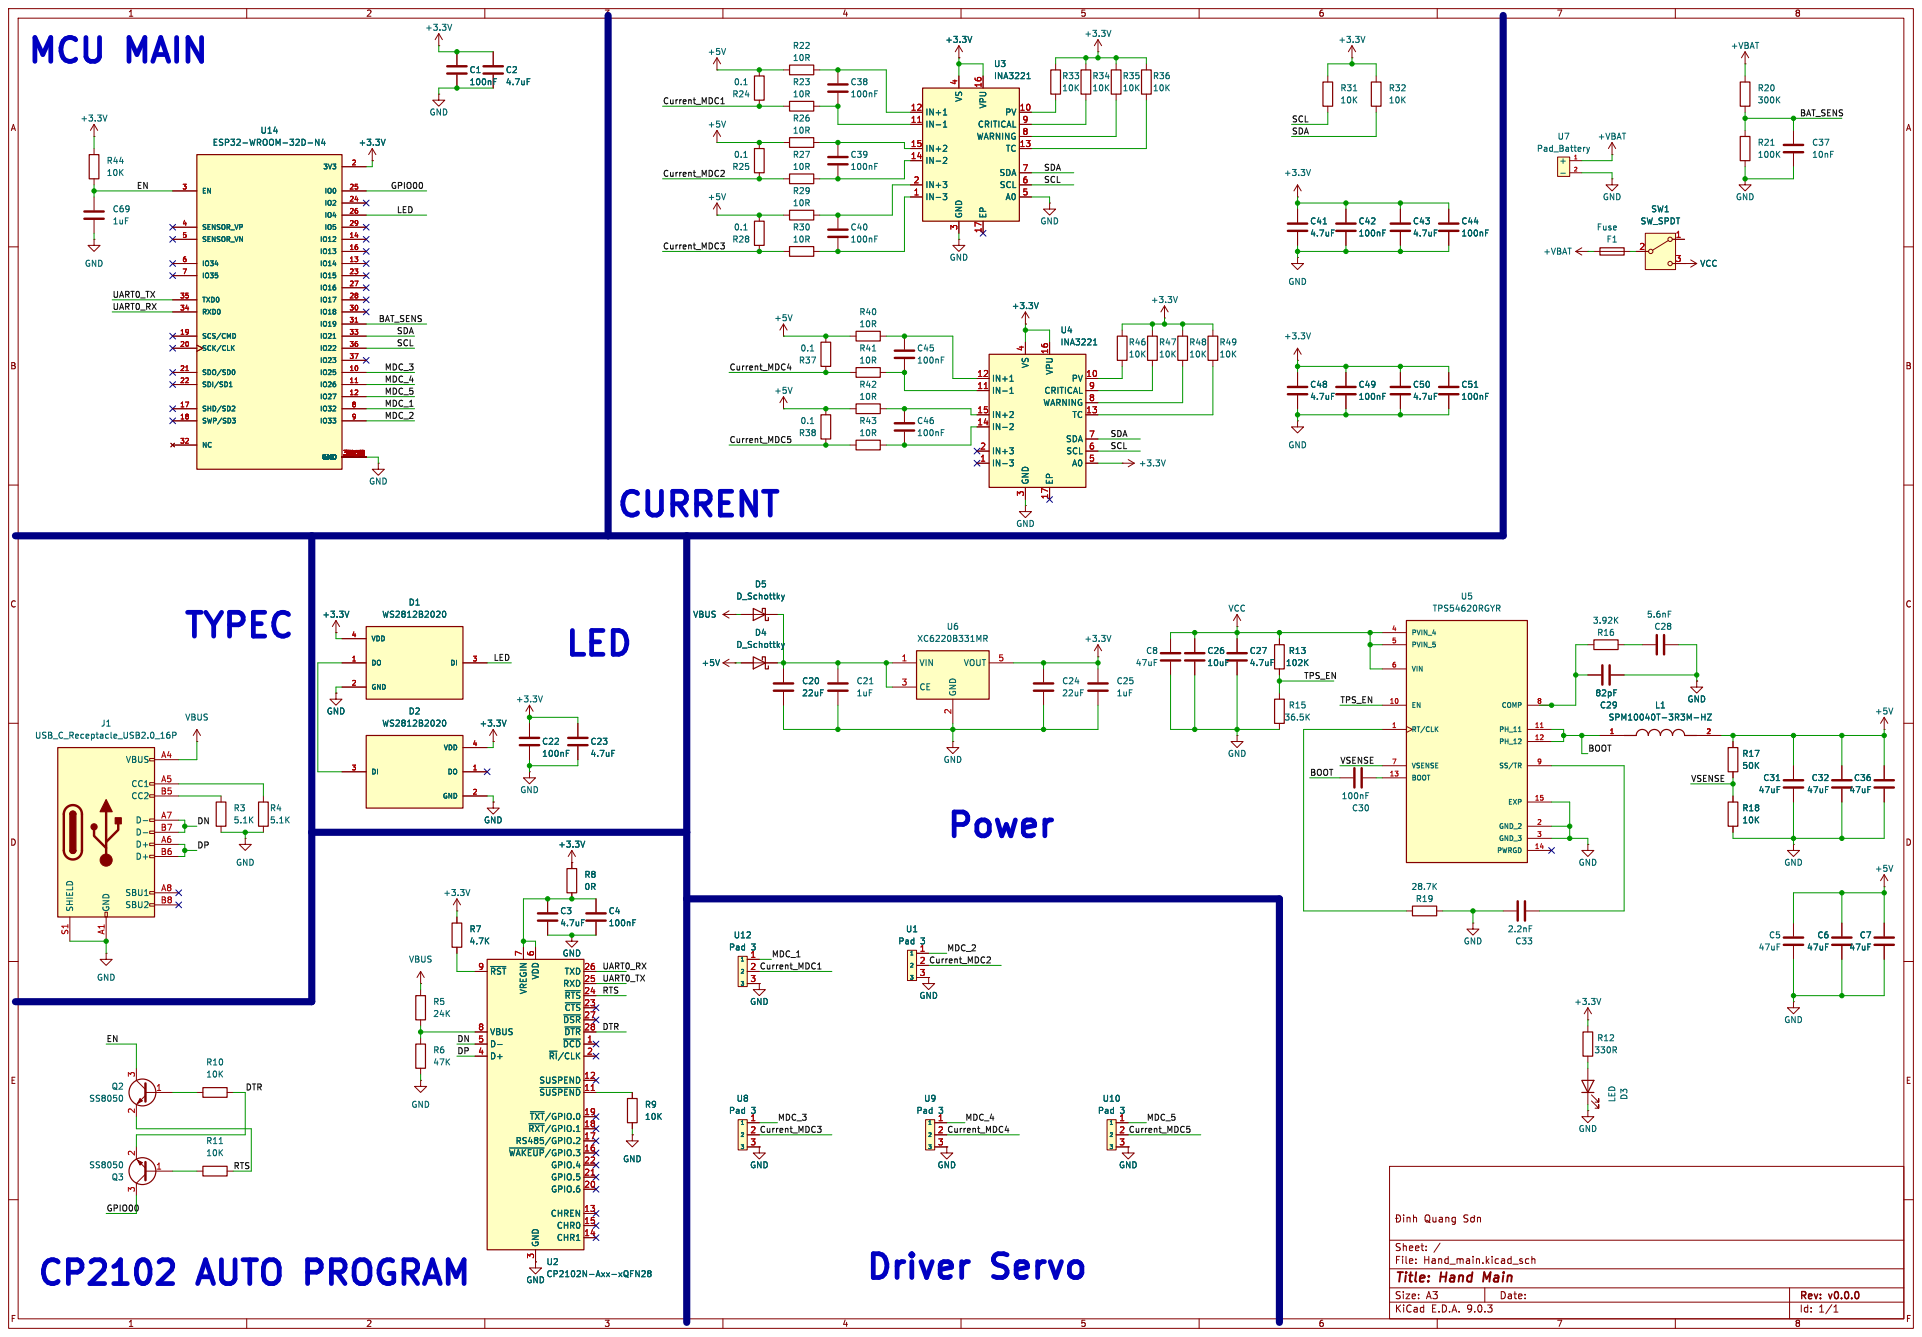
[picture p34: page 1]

3 VPU 16 EP 17 PV 10 CRITICAL 9 WARNING 8 TC 13 SDA 7 SCL 6 A0 5 +3.3V

3 VPU 16 EP 17 PV 10 CRITICAL 9 WARNING 8 TC 13 SDA 7 SCL 6 A0 5 U3

3 VPU 16 EP 17 PV 10 CRITICAL 9 WARNING 8 TC 13 SDA 7 SCL 6 A0 5 C44

3 VPU 16 EP 17 PV 10 CRITICAL 9 WARNING 8 TC 13 SDA 7 SCL 6 A0 5 U4

3 TXD 26 RXD 25 ~{RTS} 24 ~{CTS} 23 ~{DSR} 27 ~{DTR} 28 ~{DCD}1 ~{RI}/CLK2 SUSPEND 12 ~{SUSPEND}11 ~{TXT}/GPIO.019 ~{RXT}/GPIO.118 RS485/GPIO.2 17 ~{WAKEUP}/GPIO.316 GPIO.4 22 GPIO.5 21 GPIO.6 20 CHREN 13 CHR0 15 CHR1 14 U2 CP2102N-Axx-xQFN28 GND GND

3 TXD 26 RXD 25 ~{RTS} 24 ~{CTS} 23 ~{DSR} 27 ~{DTR} 28 ~{DCD}1 ~{RI}/CLK2 SUSPEND 12 ~{SUSPEND}11 ~{TXT}/GPIO.019 ~{RXT}/GPIO.118 RS485/GPIO.2 17 ~{WAKEUP}/GPIO.316 GPIO.4 22 GPIO.5 21 GPIO.6 20 CHREN 13 CHR0 15 CHR1 14 GND GND

Id: 1/1 Title: Hand Main

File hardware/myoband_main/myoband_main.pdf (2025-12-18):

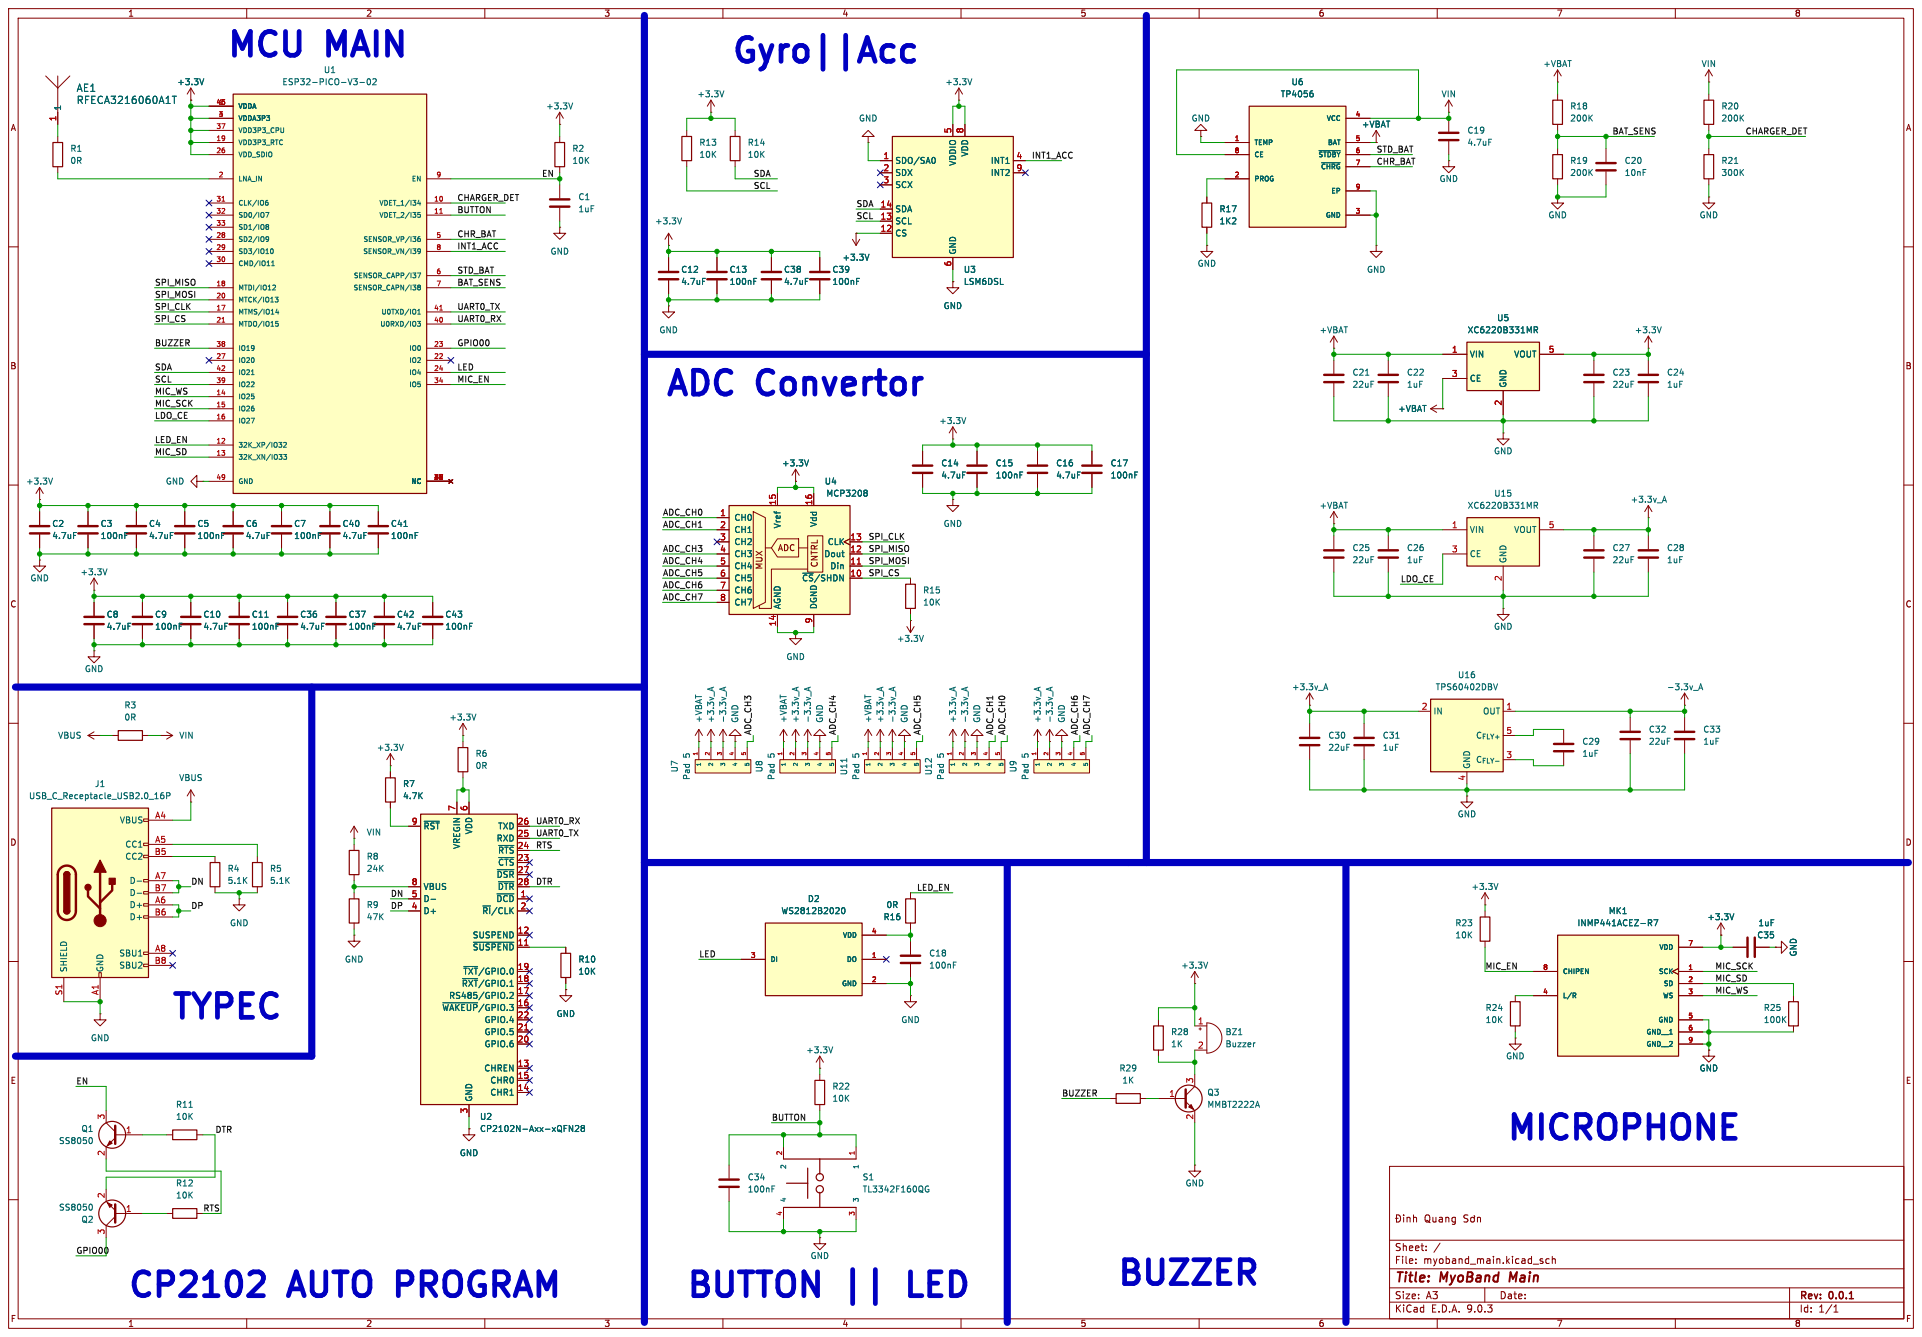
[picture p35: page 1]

+VBAT +VBAT +3.3v_A -3.3v_A GND GND

9 CLK 13 Dout 12 Din 11 ~{CS}/SHDN10 U4MCP3208 +3.3V

9 CLK 13 Dout 12 Din 11 ~{CS}/SHDN10 R16

5 U7 Pad 5 +VBAT -3.3v_A GND +VBAT +3.3v_A -3.3v_A GND

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

File: myoband_main.kicad_sch Sheet: / þÿinhQuang þÿS¡n

Id: 1/1 Title: MyoBand Main

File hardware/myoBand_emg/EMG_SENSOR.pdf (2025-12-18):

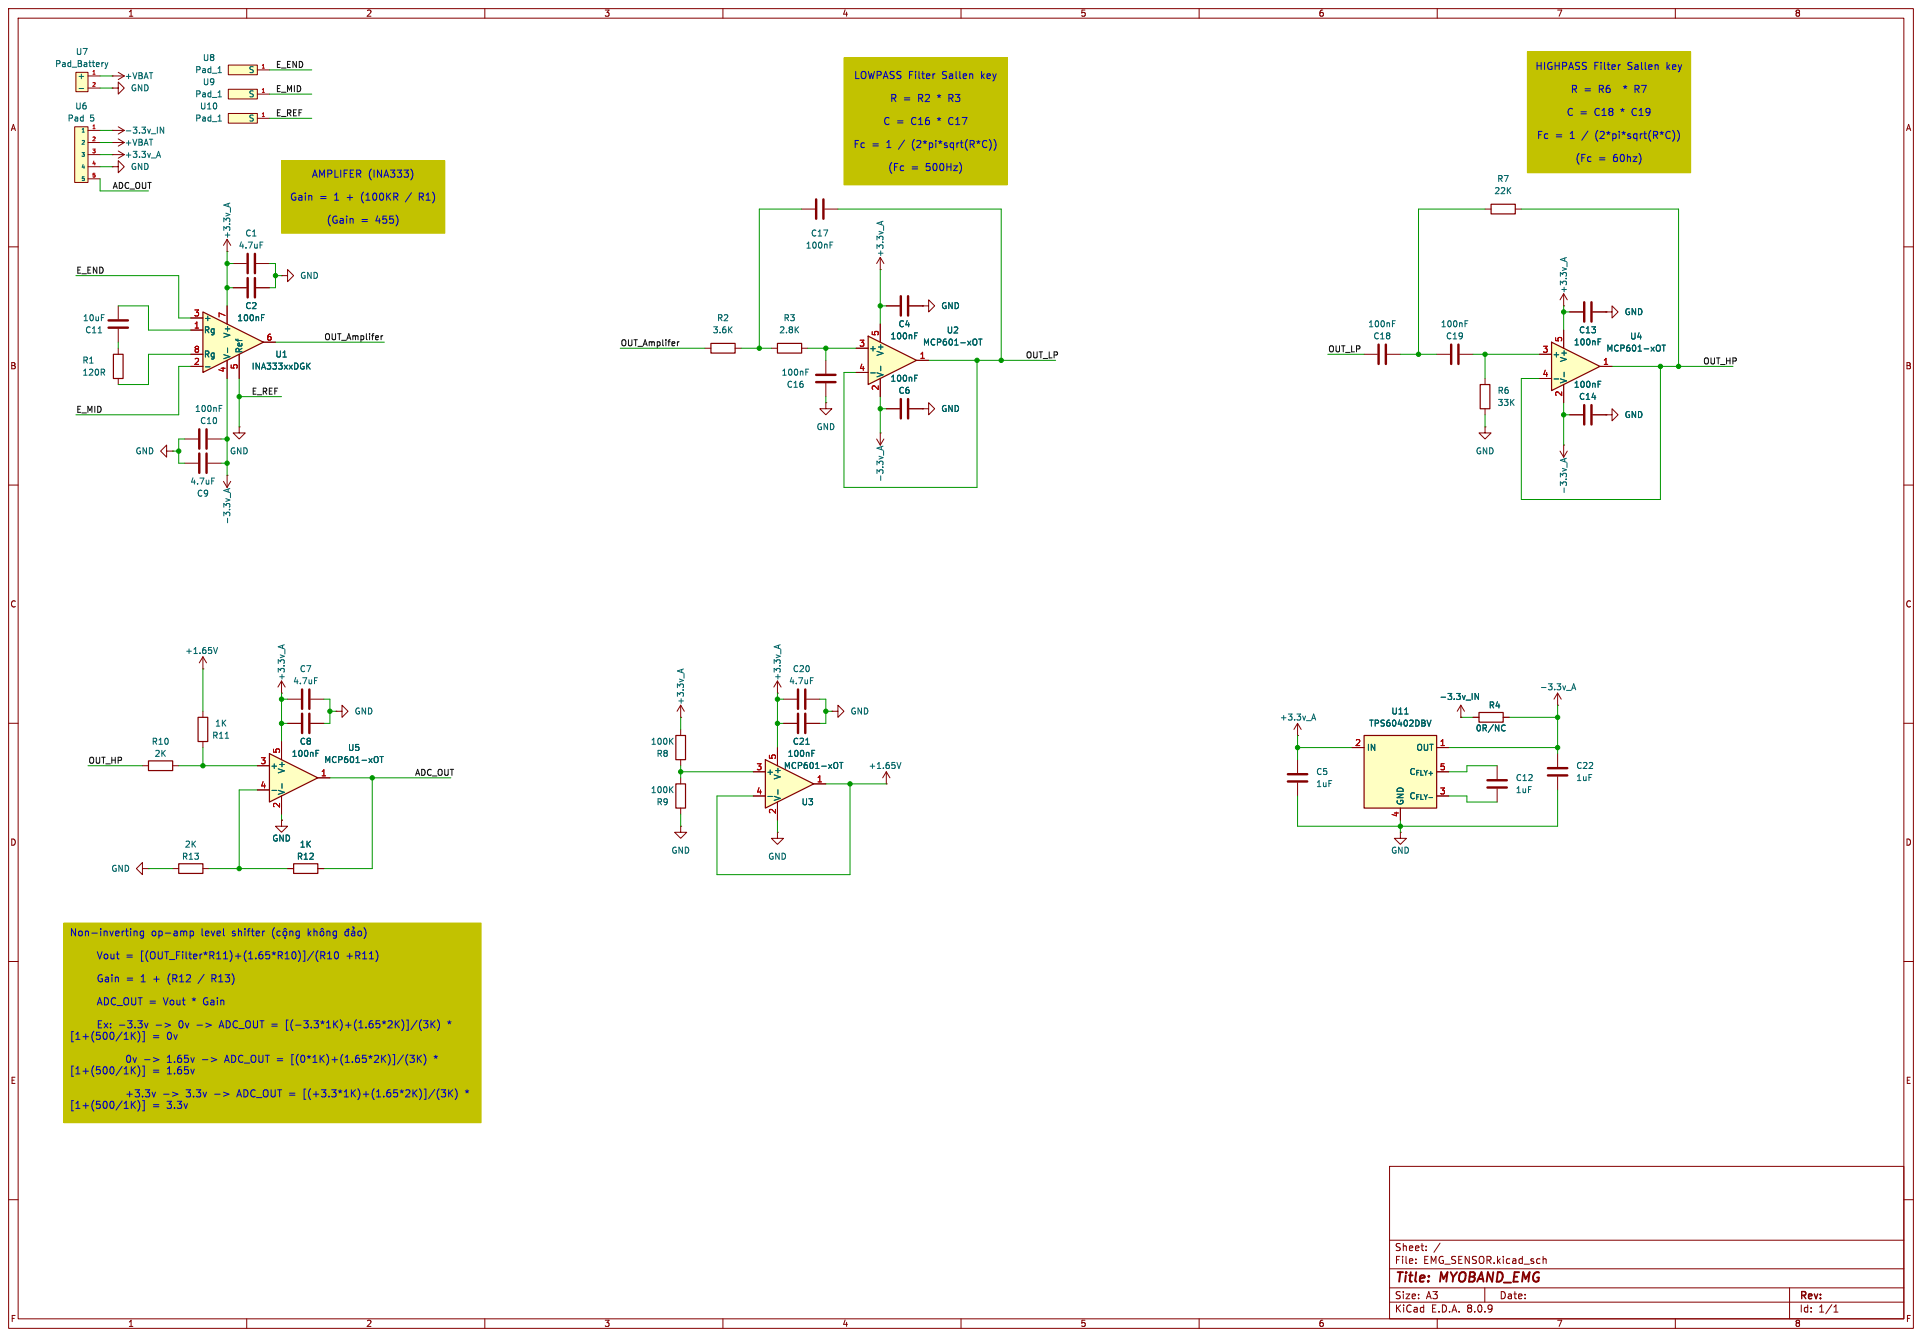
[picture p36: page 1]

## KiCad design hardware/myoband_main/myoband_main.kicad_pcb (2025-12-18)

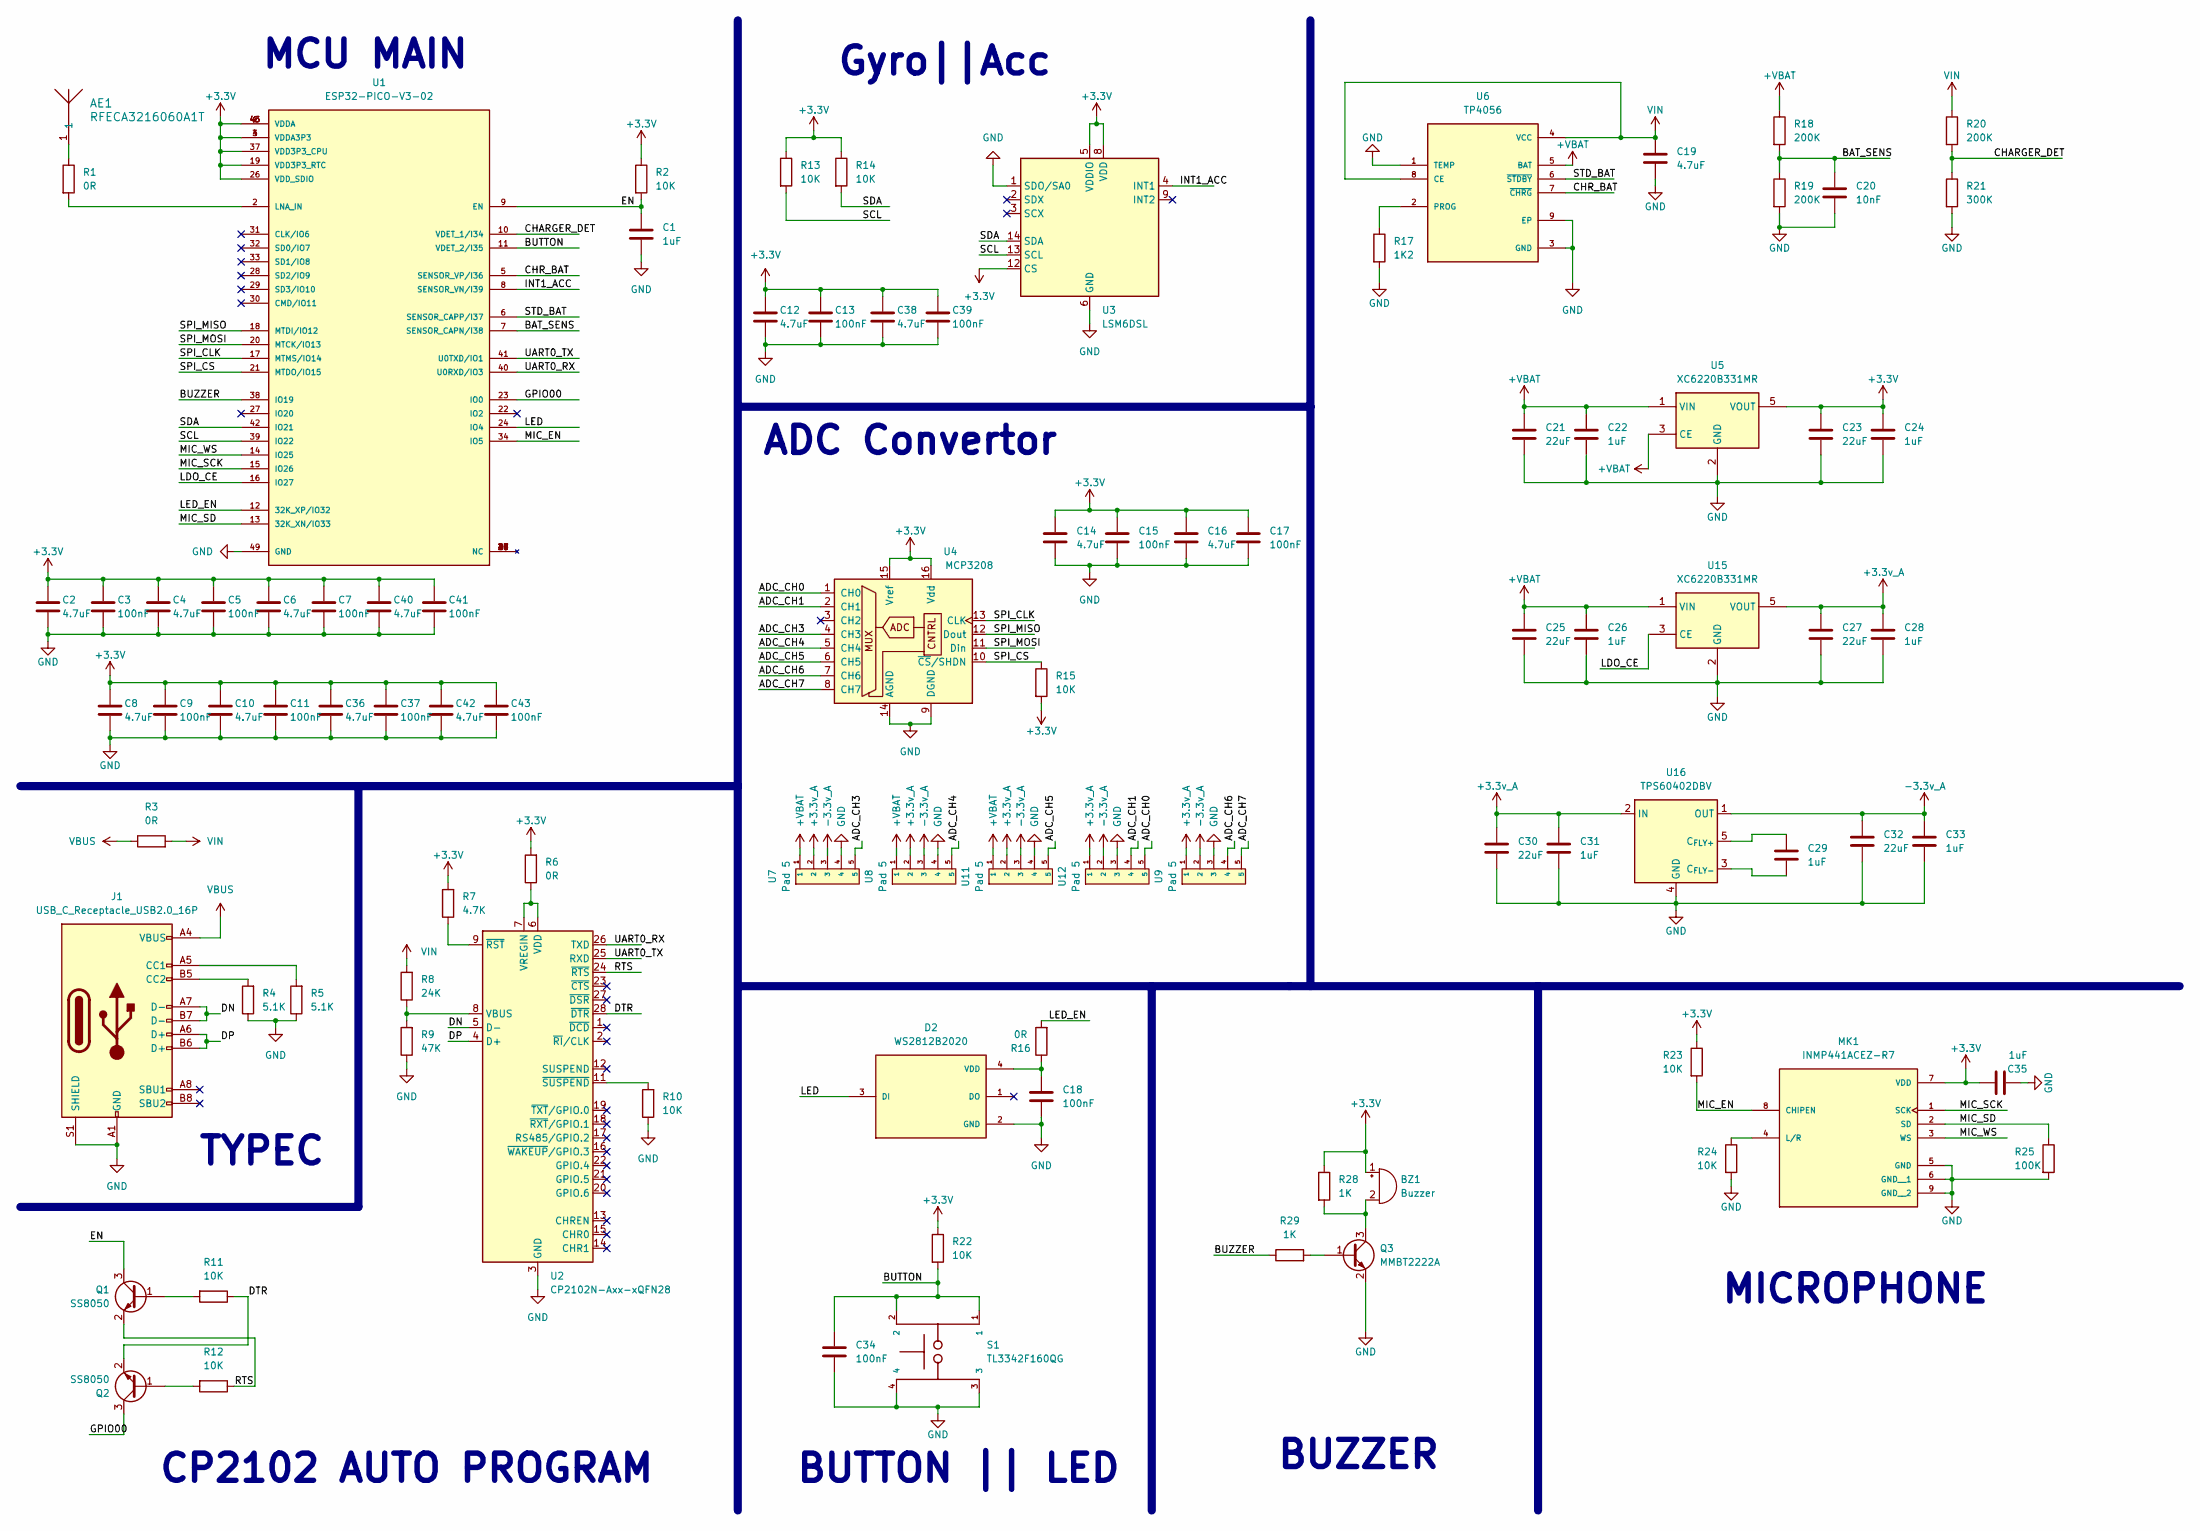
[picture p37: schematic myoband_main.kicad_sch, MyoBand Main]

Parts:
AE1: RFECA3216060A1T; ANT_16060A1T_WAL
BZ1: Buzzer; Buzzer_Murata_PKMCS0909E
C1, C22, C24, C26, C28, C29, C31, C33, C35: 1uF; C_0402_1005Metric
C2, C4, C6, C8, C10, C12, C14, C16, C19, C36, C38, C40, C42: 4.7uF; C_0402_1005Metric
C3, C5, C7, C9, C11, C13, C15, C17, C18, C34, C37, C39, C41, C43: 100nF; C_0402_1005Metric
C20: 10nF; C_0402_1005Metric
C21, C23, C25, C27, C30, C32: 22uF; C_0603_1608Metric
D2: WS2812B2020; LED_WS2812B2020; PARTREV V1.0
J1: USB_C_Receptacle_USB2.0_16P; USB_C_Receptacle_GCT_USB4105-xx-A_16P_TopMnt_Horizontal
MK1: INMP441ACEZ-R7; MIC_INMP441ACEZ-R7; PARTREV 1.1
Q1, Q2: SS8050; SOT-23
Q3: MMBT2222A; SOT-23
R1, R3, R6, R16: 0R; C_0402_1005Metric
R2, R10, R11, R12, R13, R14, R15, R22, R23, R24: 10K; C_0402_1005Metric
R4, R5: 5.1K; C_0402_1005Metric
R7: 4.7K; C_0402_1005Metric
R8: 24K; C_0402_1005Metric
R9: 47K; C_0402_1005Metric
R17: 1K2; C_0402_1005Metric
R18, R19, R20: 200K; C_0402_1005Metric
R21: 300K; C_0402_1005Metric
R25: 100K; C_0402_1005Metric
R28, R29: 1K; C_0402_1005Metric
S1: TL3342F160QG; SW_TL3342F160QG
U1: ESP32-PICO-V3-02; XCVR_ESP32-PICO-V3-02; PARTREV 1.0
U2: CP2102N-Axx-xQFN28; QFN-28-1EP_5x5mm_P0.5mm_EP3.35x3.35mm
U3: LSM6DSL; LGA-14_3x2.5mm_P0.5mm_LayoutBorder3x4y
U4: MCP3208; SOIC-16_3.9x9.9mm_P1.27mm
U5, U15: XC6220B331MR; SOT-23-5
U6: TP4056; SOP127P600X175-9N
U7, U8, U9, U11, U12: Pad 5
U16: TPS60402DBV; SOT-23-5

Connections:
+3.3V: BZ1.1 (+), C2.1, C3.1, C4.1, C5.1, C6.1, C7.1, C8.1, C9.1, C10.1, C11.1, C12.1, C13.1, C14.1, C15.1, C16.1, C17.1, C23.1, C24.1, C35.1, C36.1, C37.1, C38.1, C39.1, C40.1, C41.1, C42.1, C43.1, MK1.7 (VDD), R2.1, R6.2, R7.2, R13.1, R14.1, R15.2, R22.1, R23.1, R28.1, U1.1 (VDDA), U1.3 (VDDA3P3), U1.4 (VDDA3P3), U1.19 (VDD3P3_RTC), U1.26 (VDD_SDIO), U1.37 (VDD3P3_CPU), U1.43 (VDDA), U1.46 (VDDA), U3.5 (VDDIO), U3.8 (VDD), U3.12 (CS), U4.15 (Vref), U4.16 (Vdd), U5.5 (VOUT)
+3.3v_A: C27.1, C28.1, C30.1, C31.1, U7.2, U8.2, U9.1, U11.2, U12.1, U15.5 (VOUT), U16.2 (IN)
+VBAT: C21.1, C22.1, C25.1, C26.1, R18.1, U5.1 (VIN), U5.3 (CE), U6.5 (BAT), U7.1, U8.1, U11.1, U15.1 (VIN)
-3.3v_A: C32.1, C33.1, U7.3, U8.3, U9.2, U11.3, U12.2, U16.1 (OUT)
/ADC_CH0: U4.1 (CH0), U12.5
/ADC_CH1: U4.2 (CH1), U12.4
/ADC_CH3: U4.4 (CH3), U7.5
/ADC_CH4: U4.5 (CH4), U8.5
/ADC_CH5: U4.6 (CH5), U11.5
/ADC_CH6: U4.7 (CH6), U9.4
/ADC_CH7: U4.8 (CH7), U9.5
/BAT_SENS: C20.1, R18.2, R19.1, U1.7 (SENSOR_CAPN/I38)
/BUTTON: C34.1, R22.2, S1.1, S1.2, U1.11 (VDET_2/I35)
/BUZZER: R29.1, U1.38 (IO19)
/CHARGER_DET: R20.2, R21.1, U1.10 (VDET_1/I34)
/CHR_BAT: U1.5 (SENSOR_VP/I36), U6.7 (~CHRG)
/DN: J1.A7 (D-), J1.B7 (D-), U2.5 (D-)
/DP: J1.A6 (D+), J1.B6 (D+), U2.4 (D+)
/DTR: Q2.2 (E), R11.1, U2.28 (~DTR)
/EN: C1.1, Q1.3 (C), R2.2, U1.9 (EN)
/GPIO00: Q2.3 (C), U1.23 (IO0)
/INT1_ACC: U1.8 (SENSOR_VN/I39), U3.4 (INT1)
/LDO_CE: U1.16 (IO27), U15.3 (CE)
/LED: D2.3 (DI), U1.24 (IO4)
/LED_EN: R16.2, U1.12 (32K_XP/IO32)
/MIC_EN: MK1.8 (CHIPEN), R23.2, U1.34 (IO5)
/MIC_SCK: MK1.1 (SCK), U1.15 (IO26)
/MIC_SD: MK1.2 (SD), R25.1, U1.13 (32K_XN/IO33)
/MIC_WS: MK1.3 (WS), U1.14 (IO25)
/RTS: Q1.2 (E), R12.1, U2.24 (~RTS)
/SCL: R13.2, U1.39 (IO22), U3.13 (SCL)
/SDA: R14.2, U1.42 (IO21), U3.14 (SDA)
/SPI_CLK: U1.17 (MTMS/IO14), U4.13 (CLK)
/SPI_CS: R15.1, U1.21 (MTDO/IO15), U4.10 (~CS/SHDN)
/SPI_MISO: U1.18 (MTDI/IO12), U4.12 (Dout)
/SPI_MOSI: U1.20 (MTCK/IO13), U4.11 (Din)
/STD_BAT: U1.6 (SENSOR_CAPP/I37), U6.6 (~STDBY)
/UART0_RX: U1.40 (U0RXD/IO3), U2.26 (TXD)
/UART0_TX: U1.41 (U0TXD/IO1), U2.25 (RXD)
GND: C1.2, C2.2, C3.2, C4.2, C5.2, C6.2, C7.2, C8.2, C9.2, C10.2, C11.2, C12.2, C13.2, C14.2, C15.2, C16.2, C17.2, C18.2, C19.2, C20.2, C21.2, C22.2, C23.2, C24.2, C25.2, C26.2, C27.2, C28.2, C30.2, C31.2, C32.2, C33.2, C34.2, C35.2, C36.2, C37.2, C38.2, C39.2, C40.2, C41.2, C42.2, C43.2, D2.2 (GND), J1.A1 (GND), J1.A12 (GND), J1.B1 (GND), J1.B12 (GND), J1.S1 (SHIELD), MK1.5 (GND), MK1.6 (GND__1), MK1.9 (GND__2), Q3.2 (E), R4.1, R5.1, R9.1, R10.1, R17.2, R19.2, R21.2, R24.2, R25.2, S1.3, S1.4, U1.49 (GND), U2.3 (GND), U2.29 (GND), U3.1 (SDO/SA0), U3.6 (GND), U3.7 (GND), U4.9 (DGND), U4.14 (AGND), U5.2 (GND), U6.1 (TEMP), U6.3 (GND), U6.9 (EP), U7.4, U8.4, U9.3, U11.4, U12.3, U15.2 (GND), U16.4 (GND)
unnamed: AE1.1, R1.1
unnamed: BZ1.2 (-), Q3.3 (C), R28.2
unnamed: C18.1, D2.4 (VDD), R16.1
unnamed: J1.A5 (CC1), R5.2
unnamed: J1.B5 (CC2), R4.2
unnamed: MK1.4 (L/R), R24.1
unnamed: Q1.1 (B), R11.2
unnamed: Q2.1 (B), R12.2
unnamed: Q3.1 (B), R29.2
unnamed: R1.2, U1.2 (LNA_IN)
unnamed: R8.1, R9.2, U2.8 (VBUS)
unnamed: R6.1, U2.6 (VDD), U2.7 (VREGIN)
unnamed: R7.1, U2.9 (~RST)
unnamed: R10.2, U2.11 (~SUSPEND)
unnamed: R17.1, U6.2 (PROG)
unnamed: C29.1, U16.5 (C_{FLY+})
unnamed: C29.2, U16.3 (C_{FLY-})
VBUS: J1.A4 (VBUS), J1.A9 (VBUS), J1.B4 (VBUS), J1.B9 (VBUS), R3.1
VIN: C19.1, R3.2, R8.2, R20.1, U6.4 (VCC), U6.8 (CE)

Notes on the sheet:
MCU MAIN
TYPEC
BUTTON || LED
Gyro||Acc
MICROPHONE
CP2102 AUTO PROGRAM
BUZZER
ADC Convertor

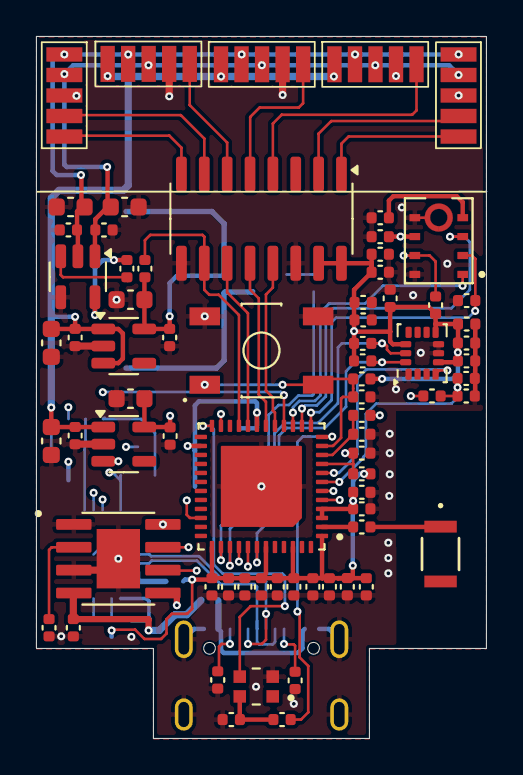
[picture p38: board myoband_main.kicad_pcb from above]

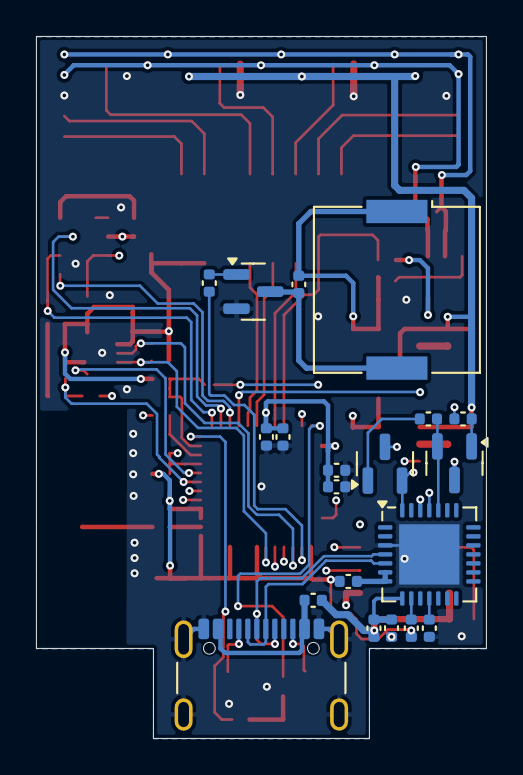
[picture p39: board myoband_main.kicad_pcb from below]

Board: 4 copper layers, 25.0 x 39.0 mm, 92 parts (20 on the bottom side), 59 nets.

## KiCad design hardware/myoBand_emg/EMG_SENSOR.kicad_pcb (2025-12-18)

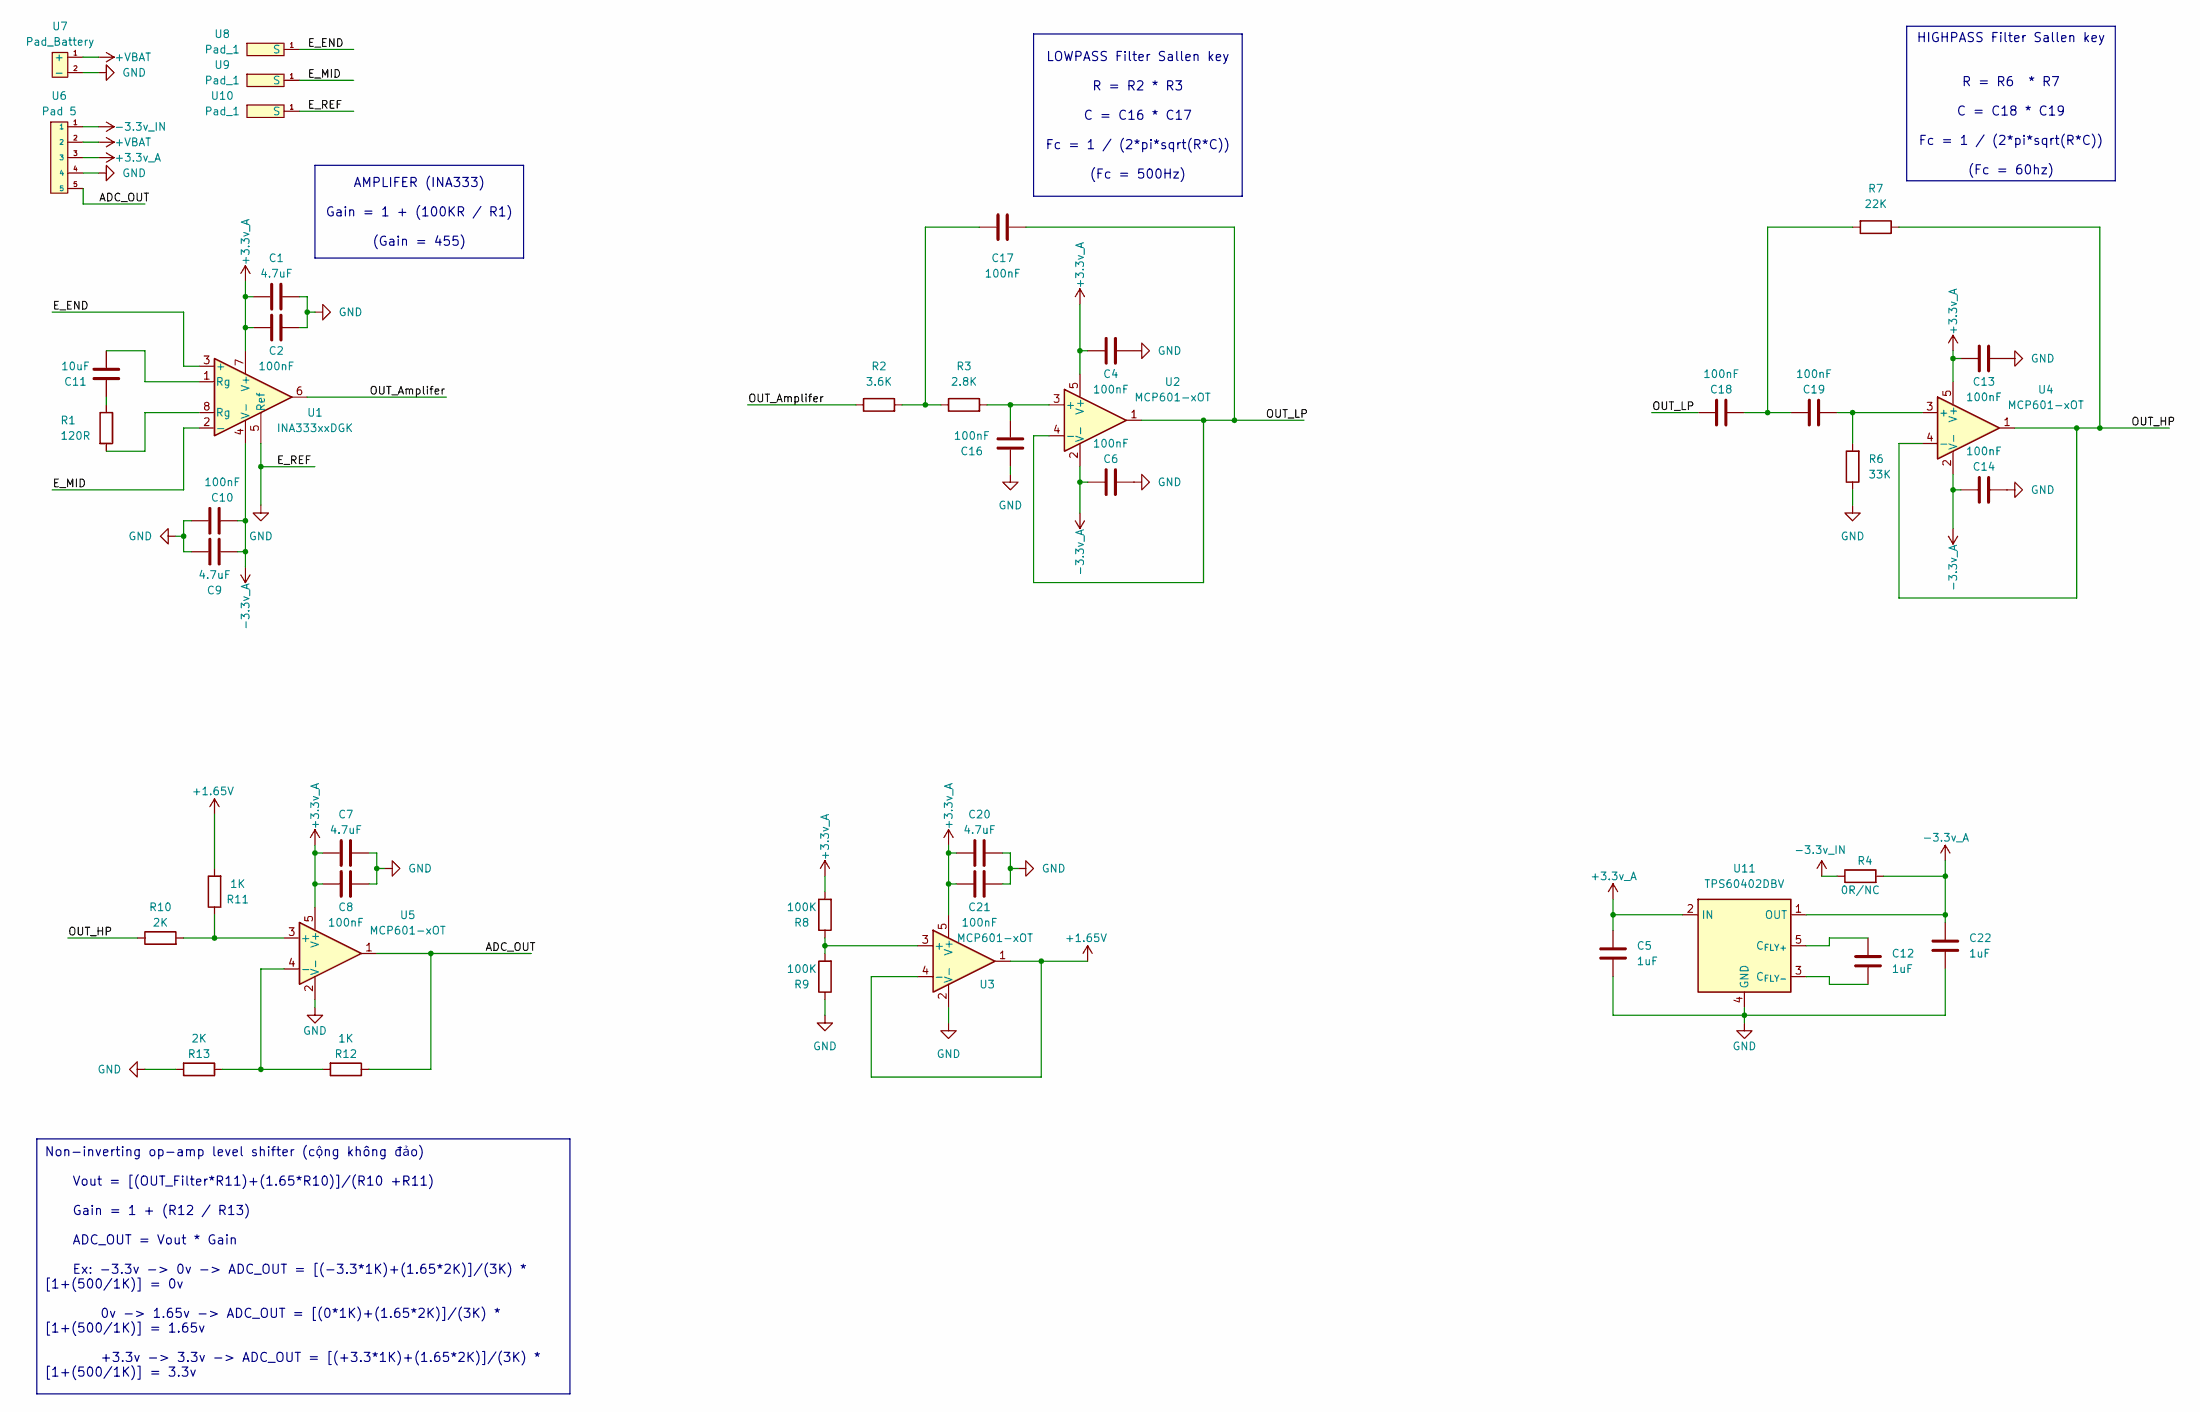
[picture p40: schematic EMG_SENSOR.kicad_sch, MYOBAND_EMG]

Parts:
C1, C7, C9, C20: 4.7uF; C_0402_1005Metric
C2, C4, C6, C8, C10, C13, C14, C16, C17, C18, C19, C21: 100nF; C_0402_1005Metric
C5, C12, C22: 1uF; C_0402_1005Metric
C11: 10uF; C_0603_1608Metric
R1: 120R; R_0402_1005Metric
R2: 3.6K; R_0402_1005Metric
R3: 2.8K; R_0402_1005Metric
R4: 0R/NC; R_0402_1005Metric
R6: 33K; R_0402_1005Metric
R7: 22K; R_0402_1005Metric
R8, R9: 100K; R_0402_1005Metric
R10, R13: 2K; R_0402_1005Metric
R11, R12: 1K; R_0402_1005Metric
U1: INA333xxDGK; VSSOP-8_3x3mm_P0.65mm
U2, U3, U4, U5: MCP601-xOT; SOT-23-5_HandSoldering
U6: Pad 5
U7: Pad_Battery; Pad Battery
U8, U9, U10: Pad_1; Pad 1
U11: TPS60402DBV; SOT-23-5

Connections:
+1.65V: R11.2, U3.1, U3.4 (-)
+3.3v_A: C1.1, C2.1, C4.1, C5.1, C7.1, C8.1, C13.1, C20.1, C21.1, R8.2, U1.7 (V+), U2.5 (V+), U3.5 (V+), U4.5 (V+), U5.5 (V+), U6.3, U11.2 (IN)
+VBAT: U6.2, U7.1 (+)
-3.3v_A: C6.2, C9.1, C10.1, C14.2, C22.1, R4.2, U1.4 (V-), U2.2 (V-), U4.2 (V-), U11.1 (OUT)
-3.3v_IN: R4.1, U6.1
/ADC_OUT: R12.1, U5.1, U6.5
/E_END: U1.3 (+), U8.1 (S)
/E_MID: U1.2 (-), U9.1 (S)
/OUT_Amplifer: R2.1, U1.6
/OUT_HP: R7.1, R10.1, U4.1, U4.4 (-)
/OUT_LP: C17.1, C18.2, U2.1, U2.4 (-)
GND: C1.2, C2.2, C4.2, C5.2, C6.1, C7.2, C8.2, C9.2, C10.2, C13.2, C14.1, C16.1, C20.2, C21.2, C22.2, R6.1, R9.1, R13.2, U1.5 (Ref), U3.2 (V-), U5.2 (V-), U6.4, U7.2 (-), U10.1 (S), U11.4 (GND)
unnamed: C11.1, R1.1
unnamed: C11.2, U1.1 (Rg)
unnamed: C17.2, R2.2, R3.1
unnamed: C18.1, C19.2, R7.2
unnamed: R1.2, U1.8 (Rg)
unnamed: C16.2, R3.2, U2.3 (+)
unnamed: R8.1, R9.2, U3.3 (+)
unnamed: C19.1, R6.2, U4.3 (+)
unnamed: R10.2, R11.1, U5.3 (+)
unnamed: R12.2, R13.1, U5.4 (-)
unnamed: C12.1, U11.5 (C_{FLY+})
unnamed: C12.2, U11.3 (C_{FLY-})

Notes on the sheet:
HIGHPASS Filter Sallen key R = R6 * R7 C = C18 * C19 Fc = 1 / (2*pi*sqrt(R*C)) (Fc = 60hz)
Non-inverting op-amp level shifter (cộng không đảo) Vout = [(OUT_Filter*R11)+(1.65*R10)]/(R10 +R11) Gain = 1 + (R12 / R13) ADC_OUT = Vout * Gain Ex: -3.3v -> 0v -> ADC_OUT = [(-3.3*1K)+(1.65*2K)]/(3K) * [1+(500/1K)] = 0v 0v -> 1.65v -> ADC_OUT = [(0*1K)+(1.65*2K)]/(3K) * [1+(500/1K)] = 1.65v +3.3v 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
LOWPASS Filter Sallen key R = R2 * R3 C = C16 * C17 Fc = 1 / (2*pi*sqrt(R*C)) (Fc = 500Hz)
AMPLIFER (INA333) Gain = 1 + (100KR / R1) (Gain = 455)

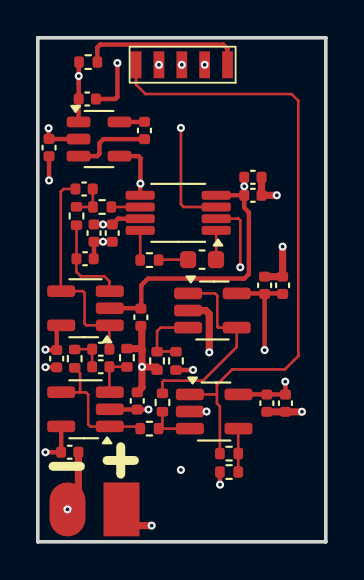
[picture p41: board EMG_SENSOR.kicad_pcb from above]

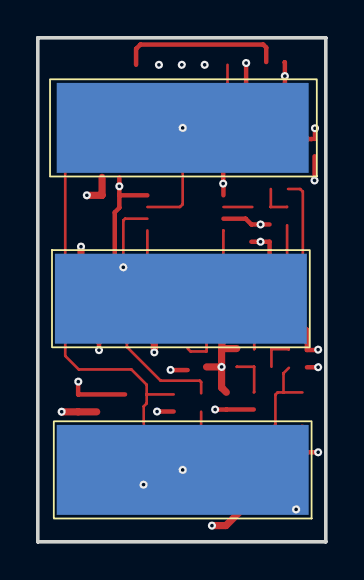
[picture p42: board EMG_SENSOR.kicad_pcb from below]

Board: 4 copper layers, 16.0 x 28.0 mm, 43 parts (3 on the bottom side), 24 nets.

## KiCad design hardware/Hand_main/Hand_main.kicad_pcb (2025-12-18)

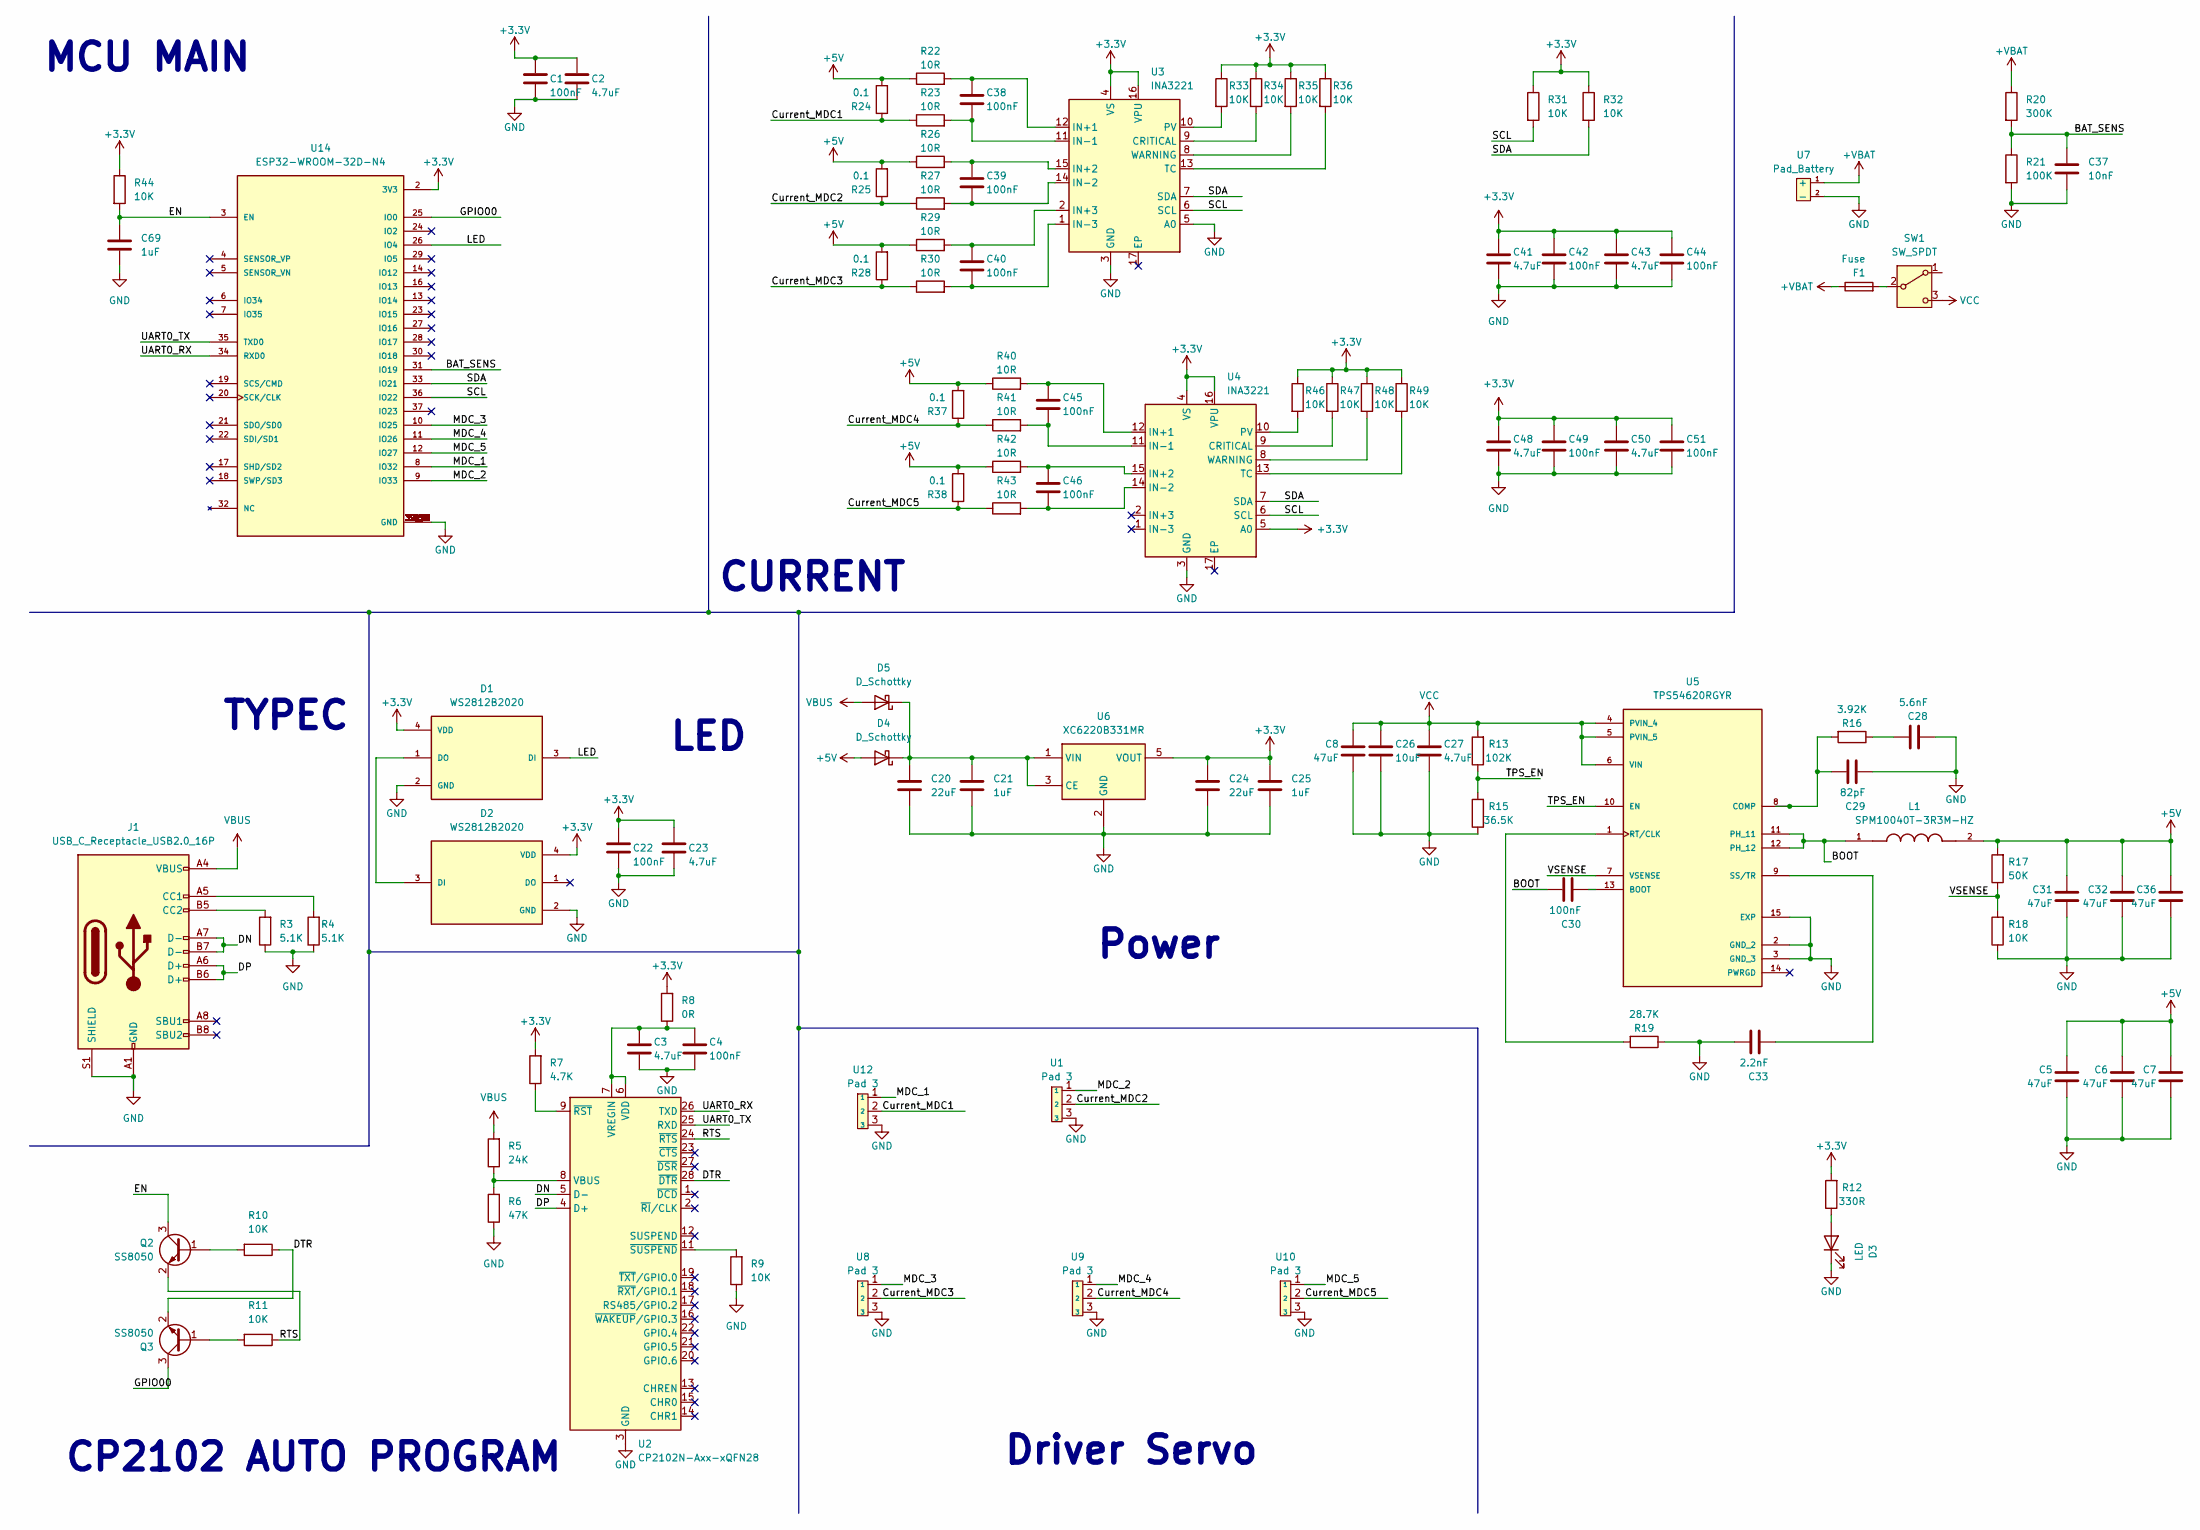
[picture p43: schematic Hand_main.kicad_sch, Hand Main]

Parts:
C1, C4, C22, C30, C38, C39, C40, C42, C44, C45, C46, C49, C51: 100nF; C_0402_1005Metric
C2, C3, C23, C41, C43, C48, C50: 4.7uF; C_0402_1005Metric
C5, C6, C7, C8, C31, C32, C36: 47uF; C_0805_2012Metric
C20, C24: 22uF; C_0603_1608Metric
C21, C25: 1uF; C_0603_1608Metric
C26: 10uF; C_0603_1608Metric
C27: 4.7uF; C_0603_1608Metric
C28: 5.6nF; C_0402_1005Metric
C29: 82pF; C_0402_1005Metric
C33: 2.2nF; C_0402_1005Metric
C37: 10nF; C_0402_1005Metric
C69: 1uF; C_0402_1005Metric
D1, D2: WS2812B2020; LED_WS2812B2020; PARTREV V1.0
D3: LED; LED_0805_2012Metric
D4, D5: D_Schottky; D_SOD-123
F1: Fuse; Fuse_1812_4532Metric
J1: USB_C_Receptacle_USB2.0_16P; USB_C_Receptacle_GCT_USB4105-xx-A_16P_TopMnt_Horizontal
L1: SPM10040T-3R3M-HZ; IND_SPM10040T-3R3M-HZ; PARTREV 20210512
Q2, Q3: SS8050; SOT-23
R3, R4: 5.1K; C_0402_1005Metric
R5: 24K; C_0402_1005Metric
R6: 47K; C_0402_1005Metric
R7: 4.7K; C_0402_1005Metric
R8: 0R; C_0402_1005Metric
R9, R10, R11, R18, R31, R32, R33, R34, R35, R36, R44, R46, R47, R48, R49: 10K; C_0402_1005Metric
R12: 330R; C_0402_1005Metric
R13: 102K; C_0402_1005Metric
R15: 36.5K; C_0402_1005Metric
R16: 3.92K; C_0402_1005Metric
R17: 50K; C_0402_1005Metric
R19: 28.7K; C_0402_1005Metric
R20: 300K; C_0402_1005Metric
R21: 100K; C_0402_1005Metric
R22, R23, R26, R27, R29, R30, R40, R41, R42, R43: 10R; C_0402_1005Metric
R24, R25, R28, R37, R38: 0.1; R_2512_6332Metric
SW1: SW_SPDT; SS-12D06G5
U1, U8, U9, U10, U12: Pad 3
U2: CP2102N-Axx-xQFN28; QFN-28-1EP_5x5mm_P0.5mm_EP3.35x3.35mm
U3, U4: INA3221; Texas_RGV0016A_VQFN-16-1EP_4x4mm_P0.65mm_EP2.1x2.1mm
U5: TPS54620RGYR; QFN50P350X350X100-15N; PARTREV 06/2011
U6: XC6220B331MR; SOT-23-5
U7: Pad_Battery; JST_XH_B2B-XH-AM_1x02_P2.50mm_Vertical
U14: ESP32-WROOM-32D-N4; ESP32-WROOM-32D; PARTREV 1.9

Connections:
+3.3V: C1.1, C2.1, C22.1, C23.1, C24.1, C25.1, C41.1, C42.1, C43.1, C44.1, C48.1, C49.1, C50.1, C51.1, D1.4 (VDD), D2.4 (VDD), R7.2, R8.2, R12.2, R31.1, R32.1, R33.1, R34.1, R35.1, R36.1, R44.1, R46.1, R47.1, R48.1, R49.1, U3.4 (VS), U3.16 (VPU), U4.4 (VS), U4.5 (A0), U4.16 (VPU), U6.5 (VOUT), U14.2 (3V3)
+5V: C5.2, C6.2, C7.2, C31.2, C32.2, C36.2, D4.2 (A), L1.2, R17.2, R22.1, R24.2, R25.2, R26.1, R28.2, R29.1, R37.2, R38.2, R40.1, R42.1
+VBAT: F1.1, R20.1, U7.1 (+)
/BAT_SENS: C37.1, R20.2, R21.1, U14.31 (IO19)
/BOOT: C30.1, L1.1, U5.11 (PH_11), U5.12 (PH_12)
/Current_MDC1: R23.1, R24.1, U12.2
/Current_MDC2: R25.1, R27.1, U1.2
/Current_MDC3: R28.1, R30.1, U8.2
/Current_MDC4: R37.1, R41.1, U9.2
/Current_MDC5: R38.1, R43.1, U10.2
/DN: J1.A7 (D-), J1.B7 (D-), U2.5 (D-)
/DP: J1.A6 (D+), J1.B6 (D+), U2.4 (D+)
/DTR: Q3.2 (E), R10.1, U2.28 (~DTR)
/EN: C69.1, Q2.3 (C), R44.2, U14.3 (EN)
/GPIO00: Q3.3 (C), U14.25 (IO0)
/LED: D1.3 (DI), U14.26 (IO4)
/MDC_1: U12.1, U14.8 (IO32)
/MDC_2: U1.1, U14.9 (IO33)
/MDC_3: U8.1, U14.10 (IO25)
/MDC_4: U9.1, U14.11 (IO26)
/MDC_5: U10.1, U14.12 (IO27)
/RTS: Q2.2 (E), R11.1, U2.24 (~RTS)
/SCL: R31.2, U3.6 (SCL), U4.6 (SCL), U14.36 (IO22)
/SDA: R32.2, U3.7 (SDA), U4.7 (SDA), U14.33 (IO21)
/TPS_EN: R13.1, R15.2, U5.10 (EN)
/UART0_RX: U2.26 (TXD), U14.34 (RXD0)
/UART0_TX: U2.25 (RXD), U14.35 (TXD0)
/VSENSE: R17.1, R18.2, U5.7 (VSENSE)
GND: C1.2, C2.2, C3.2, C4.2, C5.1, C6.1, C7.1, C8.1, C20.2, C21.2, C22.2, C23.2, C24.2, C25.2, C26.2, C27.2, C28.2, C29.2, C31.1, C32.1, C33.1, C36.1, C37.2, C41.2, C42.2, C43.2, C44.2, C48.2, C49.2, C50.2, C51.2, C69.2, D1.2 (GND), D2.2 (GND), D3.1 (K), J1.A1 (GND), J1.A12 (GND), J1.B1 (GND), J1.B12 (GND), J1.S1 (SHIELD), R3.1, R4.1, R6.1, R9.1, R15.1, R18.1, R19.1, R21.2, U1.3, U2.3 (GND), U2.29 (GND), U3.3 (GND), U3.5 (A0), U4.3 (GND), U5.2 (GND_2), U5.3 (GND_3), U5.15 (EXP), U6.2 (GND), U7.2 (-), U8.3, U9.3, U10.3, U12.3, U14.1 (GND), U14.15 (GND), U14.38 (GND), U14.39_1 (GND), U14.39_2 (GND), U14.39_3 (GND), U14.39_4 (GND), U14.39_5 (GND), U14.39_6 (GND), U14.39_7 (GND), U14.39_8 (GND), U14.39_9 (GND), U14.39_10 (GND), U14.39_11 (GND), U14.39_12 (GND), U14.39_13 (GND), U14.39_14 (GND), U14.39_15 (GND), U14.39_16 (GND), U14.39_17 (GND), U14.39_18 (GND), U14.39_19 (GND), U14.39_20 (GND), U14.39_21 (GND)
unnamed: C28.1, R16.1
unnamed: D1.1 (DO), D2.3 (DI)
unnamed: D3.2 (A), R12.1
unnamed: C20.1, C21.1, D4.1 (K), D5.1 (K), U6.1 (VIN), U6.3 (CE)
unnamed: J1.A5 (CC1), R4.2
unnamed: J1.B5 (CC2), R3.2
unnamed: Q2.1 (B), R10.2
unnamed: Q3.1 (B), R11.2
unnamed: F1.2, SW1.2 (B)
unnamed: R5.1, R6.2, U2.8 (VBUS)
unnamed: C3.1, C4.1, R8.1, U2.6 (VDD), U2.7 (VREGIN)
unnamed: R7.1, U2.9 (~RST)
unnamed: R9.2, U2.11 (~SUSPEND)
unnamed: R34.2, U3.9 (CRITICAL)
unnamed: C38.1, R22.2, U3.12 (IN+1)
unnamed: C39.1, R26.2, U3.15 (IN+2)
unnamed: C40.1, R29.2, U3.2 (IN+3)
unnamed: C38.2, R23.2, U3.11 (IN-1)
unnamed: C39.2, R27.2, U3.14 (IN-2)
unnamed: C40.2, R30.2, U3.1 (IN-3)
unnamed: R33.2, U3.10 (PV)
unnamed: R36.2, U3.13 (TC)
unnamed: R35.2, U3.8 (WARNING)
unnamed: R47.2, U4.9 (CRITICAL)
unnamed: C45.1, R40.2, U4.12 (IN+1)
unnamed: C46.1, R42.2, U4.15 (IN+2)
unnamed: C45.2, R41.2, U4.11 (IN-1)
unnamed: C46.2, R43.2, U4.14 (IN-2)
unnamed: R46.2, U4.10 (PV)
unnamed: R49.2, U4.13 (TC)
unnamed: R48.2, U4.8 (WARNING)
unnamed: C30.2, U5.13 (BOOT)
unnamed: C29.1, R16.2, U5.8 (COMP)
unnamed: R19.2, U5.1 (RT/CLK)
unnamed: C33.2, U5.9 (SS/TR)
VBUS: D5.2 (A), J1.A4 (VBUS), J1.A9 (VBUS), J1.B4 (VBUS), J1.B9 (VBUS), R5.2
VCC: C8.2, C26.1, C27.1, R13.2, SW1.3 (C), U5.4 (PVIN_4), U5.5 (PVIN_5), U5.6 (VIN)

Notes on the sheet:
CP2102 AUTO PROGRAM
Power
CURRENT
TYPEC
Driver Servo
MCU MAIN
LED

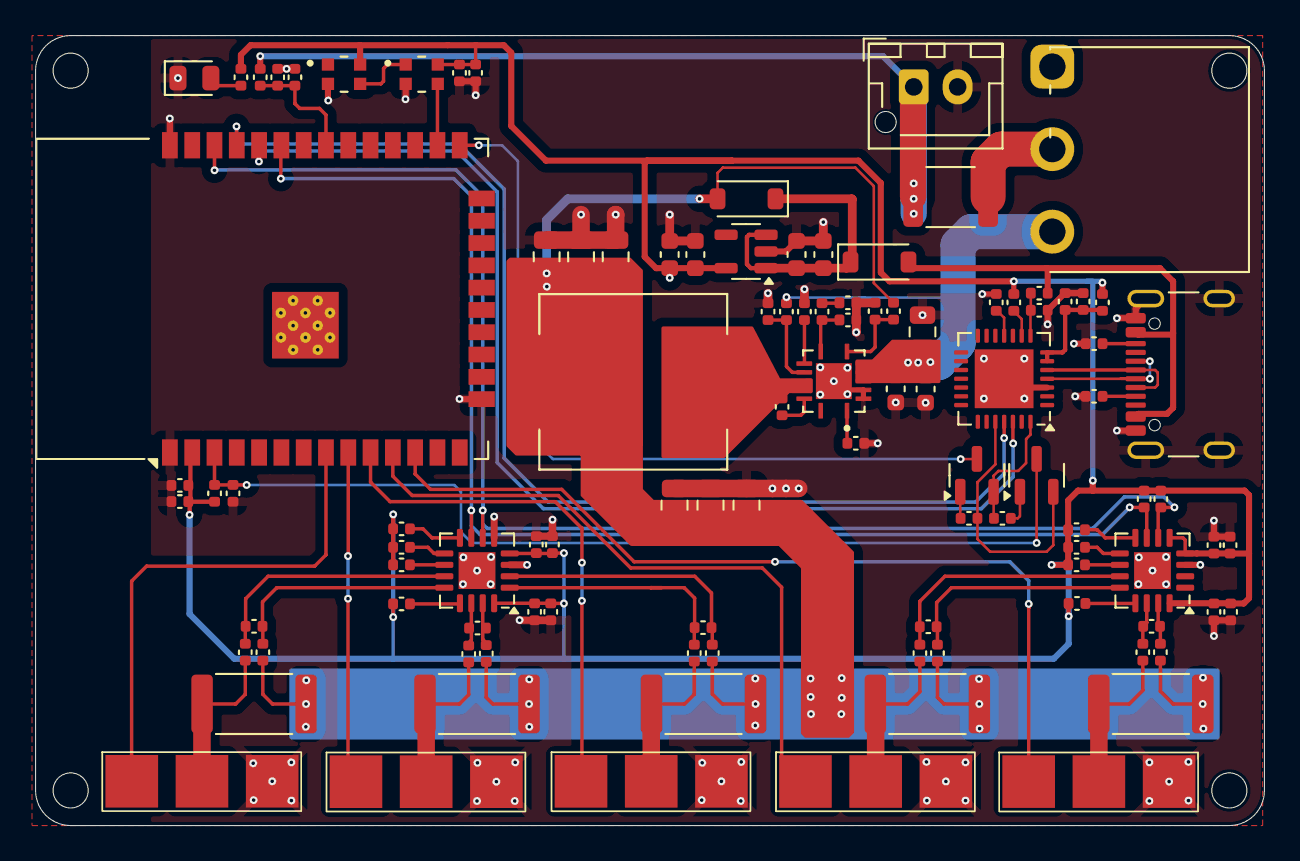
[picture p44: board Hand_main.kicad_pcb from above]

Board: 4 copper layers, 70.0 x 45.0 mm, 105 parts (0 on the bottom side), 66 nets.

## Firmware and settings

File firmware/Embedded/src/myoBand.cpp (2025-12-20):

#include <Arduino.h>
#include <esp_task_wdt.h>
#include <Adafruit_NeoPixel.h>
#include "esp_adc_cal.h"
#include "freertos/FreeRTOS.h"
#include "BLERingManager.h"
#include "EMGSensor.h"
#include "BuzzerMusic.h"

#define DEBUG
#define WDT_TIMEOUT   120

#define SPI_CS    	15 		   // SPI slave select
#define ADC_CLK     8000000  // SPI clock 1.6MHz

#define PIN_LDO_CE      27
#define PIN_BUTTON      35

#define PIN_CHARGER     34
#define PIN_STD_BAT     36
#define PIN_CHR_BAT     37
#define PIN_BAT         38

#define PIN_BITMASK     0x400000000 // 2^33 in hex

#define PIN_RGB           4
#define PIN_LED_EN        32

#define PIN_MIC_EN        5

#define TIME_WAKEUP   1500
#define BATTERY_MAX   4150
#define BATTERY_MIN   3200

TaskHandle_t task_handle_emg_signal;
TaskHandle_t task_handle_ble_emg_signal;
TaskHandle_t task_handle_ring;
TaskHandle_t task_handle_mode;

SPIClass spiMCP3208(HSPI);
MCP3208 adc(ADC_VREF, SPI_CS, &spiMCP3208);

Adafruit_NeoPixel pixels = Adafruit_NeoPixel(1, PIN_RGB, NEO_GRB + NEO_KHZ800);
BuzzerMusic buzzer;
EMGSensor emgSensor(adc, pixels, buzzer);
BLERingManager ble(emgSensor);

int8_t stateControl = 0;
uint8_t stateSensor = 0;
uint8_t mode = 0;
uint8_t connectedCountBLE = 0;
bool stateSleep = true;
bool isStreamBLE = false;

void deepSleep();
void onSleep(bool _stateSleep);
void onWakeUp();
void onPower();
void onCharger();
uint8_t getBattery();

void ReadSensorBLEOP(void* pParamter) {
  static int8_t lastStateControl = 0;
  static uint32_t lastTimeControl = millis();
  vTaskSuspend(NULL);
  for(;;) {
    ble.notifyData(1);
    if (millis() - lastTimeControl > 250) {
      ble.sendControl(stateControl);
      lastTimeControl = millis();
    }
    vTaskDelay(5);
  }
}

void ReadSensorOP(void* pParamter) {
  static uint32_t timePrint = millis();
  for(;;) {
    stateControl = emgSensor.sync(isStreamBLE);

    if (millis() - timePrint >= 250) {
      switch (stateControl) {
        case -1:
          emgSensor.setLed(0, 255, 0);
          break;

        case 1:
          emgSensor.setLed(0, 0, 255);
          break;

        case 2:
          emgSensor.setLed(255, 0, 0);
          break;

        default:
          emgSensor.setLed(0, 0, 0);
          break;
      }
      timePrint = millis();
    }
    vTaskDelay(1); 
  }
}

void ModeOP(void* pParamter) {
  int8_t lastState = 0;
  uint32_t lastTime = millis();
  vTaskSuspend(NULL);
  ble.notifyBatery(getBattery());
  for(;;) {
    int8_t _state = stateControl;
    if (lastState != _state) {
      ble.sendControl(_state);
      lastState = _state;
    }
    if (millis() - lastTime > 5000) {
      ble.notifyBatery(getBattery());
      lastTime = millis();
    }
    vTaskDelay(8);
  }
}

void RingOP(void* pParamter) {
  for(;;) {
    connectedCountBLE = ble.getCountDevice();
    // Serial.printf("connectedCountBLE %d\n", connectedCountBLE);
    if((connectedCountBLE !=0) && (!ble.isOnOTA())) {
      stateSensor = ble.getModeReadSensor();
      if (stateSensor == 1) {
        isStreamBLE = true;
        vTaskSuspend(task_handle_mode);
        vTaskResume(task_handle_emg_signal);
        vTaskResume(task_handle_ble_emg_signal);
      }else {
        isStreamBLE = false;
        vTaskSuspend(task_handle_ble_emg_signal);
        vTaskResume(task_handle_mode);
        vTaskResume(task_handle_emg_signal);
      }
      // Serial.println("use");
    }
    else {
      isStreamBLE = false;
      vTaskSuspend(task_handle_ble_emg_signal);
      vTaskSuspend(task_handle_mode);
      vTaskSuspend(task_handle_emg_signal);
      Serial.println("disconnect or update");
    }
    onPower();
    vTaskDelay(150);
  }
}

void setup() {
  Serial.begin(9600);
  delay(100);
  Serial.println("Myoband version 0.1");
  gpio_deep_sleep_hold_dis();

  pinMode(PIN_LED_EN, OUTPUT);
  digitalWrite(PIN_LED_EN, HIGH);
	pinMode(PIN_LDO_CE, OUTPUT);
	digitalWrite(PIN_LDO_CE, HIGH);

  pinMode(SPI_CS, OUTPUT);
  digitalWrite(SPI_CS, HIGH);

  pinMode(PIN_BUTTON, INPUT);
  pinMode(PIN_CHARGER, INPUT_PULLDOWN);
  pinMode(PIN_CHR_BAT, INPUT_PULLUP);
  pinMode(PIN_STD_BAT, INPUT_PULLUP);
  
  buzzer.begin();
  // buzzer.offBuzzer();

  pixels.begin();
  pixels.setBrightness(10);
	pixels.clear();
	pixels.show();

  Serial.printf("State sleep: %d\n", stateSleep);

  onWakeUp();

  SPISettings settings(ADC_CLK, MSBFIRST, SPI_MODE0);
  spiMCP3208.begin();
  spiMCP3208.beginTransaction(settings);

  esp_task_wdt_init(WDT_TIMEOUT, true);       //  enable panic so ESP32 restarts
  esp_task_wdt_add(NULL);                     //  add current thread to WDT watch

  stateSleep = !emgSensor.begin();
  onSleep(stateSleep);

  Serial.printf("Done %d\n",stateSleep);

  ble.begin();
  Serial.println();

  stateSleep = !ble.waitConnect(PIN_BUTTON, TIME_WAKEUP);
  onSleep(stateSleep);

  Serial.println("Start");
  xTaskCreatePinnedToCore(ReadSensorOP, "ReadSensorOP", 8000, NULL, 2, &task_handle_emg_signal, 1);
  xTaskCreatePinnedToCore(ReadSensorBLEOP, "ReadSensorBLEOP", 8000, NULL, 2, &task_handle_ble_emg_signal, 0);
  xTaskCreatePinnedToCore(ModeOP, "ModeOP", 8000, NULL, 1, &task_handle_mode, 0);
  xTaskCreatePinnedToCore(RingOP, "RingOP", 5000, NULL, 1, &task_handle_ring, 0);

}

void loop() {
  esp_task_wdt_reset();
  vTaskDelay(100);
}

void onWakeUp() {
  #ifndef DEBUG
    while (digitalRead(PIN_CHARGER)) {
      onCharger();
      delay(1000);
      esp_task_wdt_reset();
    }
  #endif

  uint32_t timeWakeUp = 0;
  if (!digitalRead(PIN_BUTTON)) {
    timeWakeUp = millis();
    buzzer.playSound(play_beep);
    vTaskDelay(100);
  }
  while (!digitalRead(PIN_BUTTON)) {
    esp_task_wdt_reset();
    if (millis() - timeWakeUp > TIME_WAKEUP) {
      stateSleep = !stateSleep;
      Serial.printf("State sleep: %d\n",stateSleep);
      pixels.setPixelColor(0, pixels.Color(255, 0, 0));
      pixels.show();
      while(!digitalRead(PIN_BUTTON)) {
        esp_task_wdt_reset();
        vTaskDelay(10);
      }
      buzzer.playSound(play_beep_long);
      vTaskDelay(100);
    }
  }
  onSleep(stateSleep);
}

void onSleep(bool _stateSleep) {
  if (!_stateSleep) return;
  Serial.println("On deep sleep");
  esp_task_wdt_reset();

  digitalWrite(PIN_LED_EN, HIGH);
  pixels.setPixelColor(0, pixels.Color(255, 0 , 0));
  pixels.show();
  vTaskDelay(250);
  pixels.clear();
  pixels.show();
  vTaskDelay(250);

  pixels.setPixelColor(0, pixels.Color(255, 0 , 0));
  pixels.show();
  buzzer.playSound(play_shutdown);
  vTaskDelay(250);
  pixels.clear();
  pixels.show();

  digitalWrite(PIN_LED_EN, LOW);
  digitalWrite(PIN_LDO_CE, LOW);
  buzzer.offBuzzer();

  gpio_deep_sleep_hold_en();  

  deepSleep();
}

void deepSleep() {
  // parameter Hibernate mode
  // esp_sleep_pd_config(ESP_PD_DOMAIN_RTC_PERIPH,   ESP_PD_OPTION_AUTO);
  // esp_sleep_pd_config(ESP_PD_DOMAIN_RTC_SLOW_MEM, ESP_PD_OPTION_OFF);
  // esp_sleep_pd_config(ESP_PD_DOMAIN_RTC_FAST_MEM, ESP_PD_OPTION_OFF);
  // esp_sleep_pd_config(ESP_PD_DOMAIN_XTAL,         ESP_PD_OPTION_OFF);

  // enable RCT_IO wakeup
  esp_sleep_enable_ext0_wakeup(GPIO_NUM_35, 0);

  #ifndef DEBUG
    esp_sleep_enable_ext1_wakeup(PIN_BITMASK, ESP_EXT1_WAKEUP_ANY_HIGH);
  #endif
  esp_task_wdt_delete(NULL);

  //start sleep
  esp_deep_sleep_start();
}

uint8_t getBattery() {
  static float Vin = analogReadMilliVolts(PIN_BAT) * 2;   //resistor voltage divider
  UTILS_LOW_PASS_FILTER(Vin, analogReadMilliVolts(PIN_BAT) * 2, 0.01);
  int16_t batteryPercent = (Vin - BATTERY_MIN) / (BATTERY_MAX - BATTERY_MIN) * 100;
  batteryPercent = constrain(batteryPercent, 0, 100);

  return batteryPercent;
}

void onCharger() {
  uint8_t batteryPercent = getBattery();

  Serial.print("Battery Percent");
  Serial.print("\t");
  Serial.println(batteryPercent);

  if (batteryPercent > 90)      pixels.setPixelColor(0, pixels.Color(0, 255, 0));
  else                          pixels.setPixelColor(0, pixels.Color(255, 0, 0));
  pixels.show();
}

void onPower() {
  #ifndef DEBUG
    if (digitalRead(PIN_CHARGER)) esp_cpu_reset(1);
  #endif

  uint32_t timeWakeUp = 0;
  if (!digitalRead(PIN_BUTTON)) {
    timeWakeUp = millis();
    buzzer.playSound(play_beep);
    vTaskDelay(100);
  }
  
  while (!digitalRead(PIN_BUTTON)) {
    if (millis() - timeWakeUp > TIME_WAKEUP) {
      stateSleep = !stateSleep;
      Serial.printf("State sleep: %d\n",stateSleep);
      pixels.setPixelColor(0, pixels.Color(255, 0, 0));
      pixels.show();
      while(!digitalRead(PIN_BUTTON)) {
        esp_task_wdt_reset();
        vTaskDelay(10);
      }
      buzzer.playSound(play_beep_long);
      vTaskDelay(100);
    }
    esp_task_wdt_reset();
  }

  if (!stateSleep) {
    switch (connectedCountBLE)
    {
    case 0:
      if (!emgSensor.isReady()) {
        stateSleep = true;
        onSleep(stateSleep);
      }
      ble.startAdvertising();
      stateSleep = !ble.waitConnect(PIN_BUTTON, TIME_WAKEUP);
      if (!stateSleep) {
        if(emgSensor.isReady()) {
          // pixels.setPixelColor(0, pixels.Color(0, 255, 0));
          // pixels.show();
        }
      }
      break;
    case 1: 
      ble.startAdvertising();
      break;
    
    default:
      ble.stopAdvertising();
      break;
    }
  }

  static uint32_t lastTimeBattery = millis();
  if (millis() - lastTimeBattery > 1000) {
    uint8_t batteryPersent = getBattery();
    if (batteryPersent < 15) {
      for (uint8_t i = 0; i < 3; i++) {
        pixels.setPixelColor(0, pixels.Color(255, 0, 0));
        pixels.show();
        buzzer.playSound(play_beep_short);
        vTaskDelay(200);

        pixels.clear();
        pixels.show();
        buzzer.playSound(play_beep_short);
        vTaskDelay(200);
      }
      if (batteryPersent < 5) {
        pixels.setPixelColor(0, pixels.Color(255, 0, 0));
        pixels.show();
        buzzer.playSound(play_warning);
        vTaskDelay(2000);
        stateSleep = true;
      }
    }   
    lastTimeBattery = millis();
  }

  onSleep(stateSleep);
}

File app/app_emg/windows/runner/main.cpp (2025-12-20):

#include <flutter/dart_project.h>
#include <flutter/flutter_view_controller.h>
#include <windows.h>

#include "flutter_window.h"
#include "utils.h"

int APIENTRY wWinMain(_In_ HINSTANCE instance, _In_opt_ HINSTANCE prev,
                      _In_ wchar_t *command_line, _In_ int show_command) {
  // Attach to console when present (e.g., 'flutter run') or create a
  // new console when running with a debugger.
  if (!::AttachConsole(ATTACH_PARENT_PROCESS) && ::IsDebuggerPresent()) {
    CreateAndAttachConsole();
  }

  // Initialize COM, so that it is available for use in the library and/or
  // plugins.
  ::CoInitializeEx(nullptr, COINIT_APARTMENTTHREADED);

  flutter::DartProject project(L"data");

  std::vector<std::string> command_line_arguments =
      GetCommandLineArguments();

  project.set_dart_entrypoint_arguments(std::move(command_line_arguments));

  FlutterWindow window(project);
  Win32Window::Point origin(10, 10);
  Win32Window::Size size(1280, 720);
  if (!window.Create(L"app_emg", origin, size)) {
    return EXIT_FAILURE;
  }
  window.SetQuitOnClose(true);

  ::MSG msg;
  while (::GetMessage(&msg, nullptr, 0, 0)) {
    ::TranslateMessage(&msg);
    ::DispatchMessage(&msg);
  }

  ::CoUninitialize();
  return EXIT_SUCCESS;
}

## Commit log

2025-12-18 feature: additional drawing hardware and add information to the hardware Readme file
    [EMG_SENSOR.kicad_pcb, EMG_SENSOR.kicad_sch, Hand_main.kicad_pcb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]
2025-12-20 feature: additional firmware | fix: added some content to the readme file
    [handMain.cpp, myoBand.cpp]

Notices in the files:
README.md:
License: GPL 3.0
